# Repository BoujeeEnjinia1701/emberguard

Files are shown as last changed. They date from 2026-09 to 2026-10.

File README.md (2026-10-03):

# EmberGuard

     

**Area:** Situational Field Hardware · **TRL:** 3 of 9 (proof of concept on paper) · **Value-engineering target:** $605 USD (estimated kit cost $707) · **Difficulty:** 3 of 5

Gutter-corner thermal sensors and a weather mast that detect ember showers and trigger gutter and eave sprinkler zones.

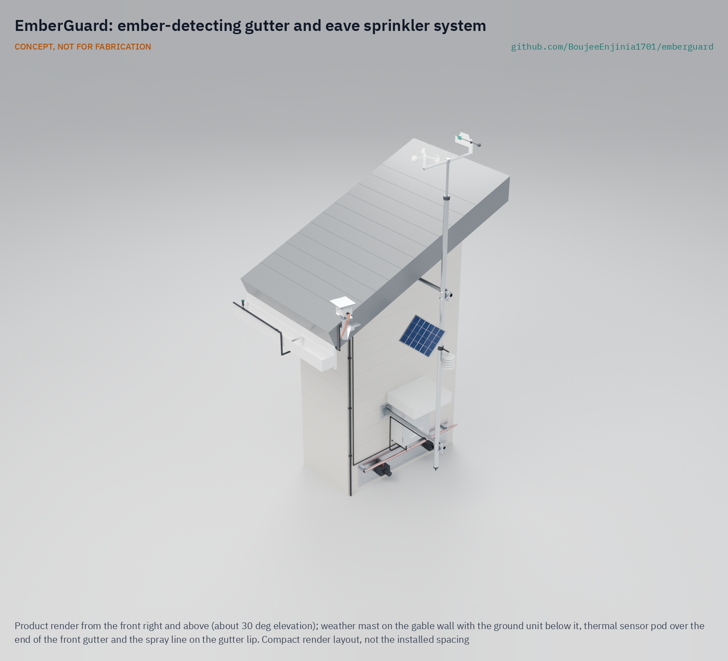
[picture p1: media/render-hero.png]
EmberGuard: ember-detecting gutter and eave sprinkler system, product render


[Exploded render](media/render-exploded.png) · [Detail render](media/render-detail.png) · [Interactive 3D model](media/viewer.html) · [Concept blueprint (PDF)](media/concept-blueprint.pdf) · [General arrangement EGD-DWG-001 (PDF)](cad/drawings/EGD-DWG-001.pdf) · [Sizing calculations](docs/04-calcs/01-sizing.md) · [Prototype build plan](docs/05-build-plan.md) · [Design decisions](docs/06-design-decisions.md) · [Review note](docs/REVIEW.md)

## Concept rationale

Most houses lost in wildland fires are lit by embers that lodge in gutters and at roof edges, often hours before or after the flame front and while the house is empty. EmberGuard therefore aims small and early: two low-cost thermal arrays look straight along the gutters from pods at their ends, a weather mast decides when fire weather has arrived, and a 4 L/min micro-sprinkler line wets only the strip where embers collect. Sensing embers rather than running on a timer keeps water use within a household tank and away from the hydrant supply that fire crews need.

The design is open and garage-buildable because the people most exposed are often the least able to buy a commercial exterior sprinkler system. Every part is an off-the-shelf sensor, irrigation valve or weather-station spare, the kit runs on 12 V with no mains work or roof penetrations, and the calculations, model and bill of materials are published so that neighbourhood groups, fire agencies and researchers can check the claims and the misses.

## Burning platform

Extreme wildfires are becoming more common. The UN Environment Programme projects a global increase in extreme fires of up to 14 % by 2030, 30 % by 2050 and 50 % by 2100 ([UNEP, 2022](https://www.unep.org/news-and-stories/press-release/number-wildfires-rise-50-cent-2100-and-governments-are-not-prepared)). At the same time more homes sit where fire can reach them: in the United States the wildland-urban interface grew from 30.8 million to 43.4 million homes between 1990 and 2010, a 41 % increase ([Radeloff et al. 2018, *PNAS*](https://doi.org/10.1073/pnas.1718850115)).

Embers are what turn a wildfire into a town fire. In the 2018 Camp Fire, showers of burning debris carried ahead of the main fire ignited buildings in Paradise, California; the fire killed 85 people and destroyed more than 18,000 buildings ([NIST, 2021](https://www.nist.gov/news-events/news/2021/02/new-timeline-deadliest-california-wildfire-could-guide-lifesaving-research)). Australia's 2019 to 2020 bushfires destroyed more than 3,000 homes ([Royal Commission into National Natural Disaster Arrangements, 2020](https://naturaldisaster.royalcommission.gov.au/publications/html-report/foreword)).

## Where it could be used

### By industry

| Industry | Use |
| --- | --- |
| Residential housing in fire-prone areas | Automatic wetting of gutters and eaves while the household is evacuated |
| Home insurance and mitigation programmes | An open, auditable reference design for studying low-cost ember defense retrofits |
| Agriculture and wine | Protecting sheds, barns and packing houses on tank water at the edge of bush or forest |
| Tourism and parks | Unattended lodges, huts and campground buildings in forest settings |
| Wildfire research | Logged ember arrival times, wind and valve actions from individual houses |

### By country or region

| Country or region | Why it matters there |
| --- | --- |
| United States (California and the West) | The Camp Fire destroyed more than 18,000 buildings, many ignited by embers blown ahead of the front ([NIST, 2021](https://www.nist.gov/news-events/news/2021/02/new-timeline-deadliest-california-wildfire-could-guide-lifesaving-research)) |
| Canada | More than 6,000 fires burned about 15 million hectares in 2023, over twice the previous record ([Natural Resources Canada](https://natural-resources.canada.ca/stories/simply-science/canada-s-record-breaking-wildfires-2023-fiery-wake-call)) |
| Australia | The 2019 to 2020 bushfires destroyed more than 3,000 homes ([Royal Commission, 2020](https://naturaldisaster.royalcommission.gov.au/publications/html-report/foreword)); many rural homes rely on tank water |
| Chile | Fires around Viña del Mar in February 2024 killed at least 122 people by 5 February ([UN Connecting Business initiative](https://www.connectingbusiness.org/ourwork/emergencies/chile-wildfires-2024)) |
| South Africa | The 2017 Knysna fires destroyed or damaged 1,059 formal and 385 informal homes, with ember attack igniting secondary fires across rivers and highways ([*International Journal of Disaster Risk Reduction*, 2023](https://www.sciencedirect.com/science/article/pii/S2212420923000985)) |
| Greece (Mediterranean Europe) | The July 2018 fire in the seaside village of Mati, near Athens, killed at least 98 people and destroyed thousands of houses and vehicles ([European Parliament, 2018](https://www.europarl.europa.eu/doceo/document/B-8-2018-0391_EN.html); [NOAA Climate.gov, 2018](https://www.climate.gov/news-features/event-tracker/strong-winds-whip-deadly-wildfires-greece-late-july-2018)) |

## What sparked the idea

The idea traces back to the survey that CSIRO building researchers made after the Ash Wednesday bushfires of 16 February 1983. Caird Ramsay and colleagues examined some 1,150 burnt and surviving houses in the Otway Ranges and found that houses were most often set alight by burning debris, embers of bark, twigs and leaves borne on the wind, lodging in gaps, at ridges and at gutters. They also found that people played a significant role in house survival, because a few buckets of water and wet mops were enough if a small fire was attacked early ([CSIRO, *Ecos* 43, 1985](https://www.aidr.org.au/media/4774/ecos_lessons-from-ash-wednesday.pdf)). EmberGuard asks whether a machine can supply that small, early wetting at the places where embers lodge, so that nobody has to stay behind to do it.

## Problem

Wildfire embers ignite homes well ahead of the fire front, most often in gutters, on roof edges and in debris near the eaves, while the house is empty and the power may be off. Commercial exterior sprinkler systems exist but are costly and closed, and timer-based sprinklers waste water that fire crews need.

## Concept

Gutter-corner thermal sensors and a weather mast that detect ember showers and trigger gutter and eave sprinkler zones.

Two small sensor pods at the gable-end corners of the gutters each hold a thermal array camera that looks straight along its gutter, and a slim weather mast at the gable carries an anemometer, wind vane, humidity sensor and solar panel. The system arms itself in fire weather, and when a pod sees a hot spot or a burst of hot specks it sprays the gutter lips at a steady 4 L/min, running only the leeward line in wind. It runs for three days armed on a small LiFePO4 battery with solar top-up.

The TRL 3 calculations (EGD-CAL-001 v0.6) confirm about 965 L per 4 h ember event, water at the farthest head within 54 s, a battery with a wide margin and a strong mast, and show that the pods see the inside of each open gutter along its length. They also show that hanger straps hide deep gutter debris beyond about 8 m, that single embers are caught to 8.8 m only when centred in a pixel, and that the leeward eave still gets too little water in the design wind. Making the design buildable (EGD-DDR-003) and the enclosure decisions of 2026-10-02 (a folded white sun shade and a charge controller that stops charging above 45 °C) bring the priced kit to an estimated $707 against the $605 value-engineering target set on 2026-09-26, USD 102 over; the savings worth trying are in the design decisions register. Paper studies of coarser spray and of pods raised to 1 m above the gutter lip left the design unchanged. The other findings are open questions for the next revision, listed in the [review note](docs/REVIEW.md).

Full design precis: [docs/02-concept.md](docs/02-concept.md)

## Key components

- Gable-end weather mast on two standoffs with crossover plates
- Two gutter-corner sensor pods with heat hoods and lens hoods, each with a thermal array sensor (32 x 24 pixels), on arms from cleats on the roof verge
- Anemometer, wind vane, temperature and humidity sensor
- Controller with 12.8 V 10 Ah LiFePO4 battery in a light-coloured steel enclosure under a folded white sun shade, and a 10 W solar panel with a charge controller that stops charging above 45 °C
- Two 12 V normally closed zone valves and a pressure transducer on a wall-mounted valve board
- Pump-start dry contact for an existing pump
- Micro-sprinkler lines on both gutter lips
- Mast earthing kit

The priced bill of materials is in [bom/bom.csv](bom/bom.csv). The parametric model is `cad/src/model.py`, with STEP and STL exports in `cad/step/` and `cad/stl/`.

## Building the prototype

The concept has been made buildable (decision record [EGD-DDR-003](docs/decisions/0003-design-for-construction.md)): every part now has a fixing and a way to be made in a small workshop, and the model checks that nothing overlaps and nothing stands in the thermal sensors' view. The [prototype build plan](docs/05-build-plan.md) shows how to make each of the 14 made or drilled components and fit the kit to a house in 18 steps, with a picture for every component, joint and step. It is a plan, not a record of a build; building and testing to it is TRL 4 work. Every decision is indexed in the [design decisions register](docs/06-design-decisions.md).

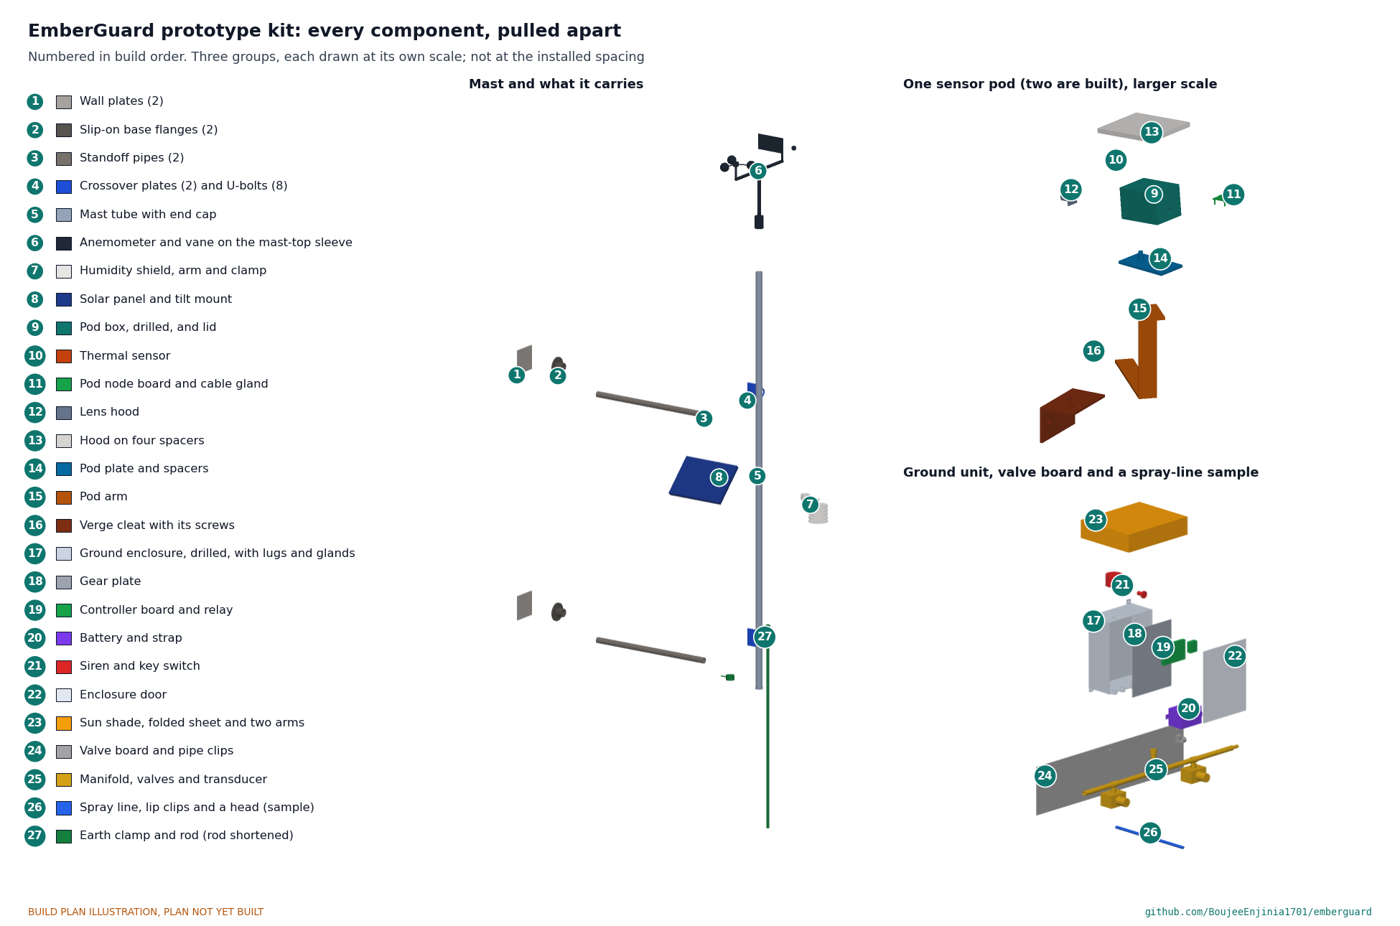
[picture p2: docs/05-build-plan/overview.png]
EmberGuard prototype kit, every component pulled apart and numbered in build order


## Safety

> Not a substitute for evacuation orders, home hardening or professional fire protection. Leave when told to leave. Installation involves work at height. The kit is 12 V DC only; a mains pump keeps its own certified controls. The LiFePO4 battery must be fused and enclosed, and the mast must be earthed against lightning. See the safety section of the precis.

## Repository layout

| Folder | Contents |
| --- | --- |
| `docs/` | Problem, concept, requirements, calculations and design decisions |
| `cad/src/` | build123d Python source, the source of truth for all geometry |
| `cad/step/`, `cad/stl/` | Exported models for FreeCAD, other CAD tools and printing |
| `cad/drawings/` | 2D sketches and dimensioned drawings |
| `bom/` | Bill of materials |
| `electronics/` | KiCad schematics and PCB layouts |
| `firmware/` | Microcontroller code |
| `media/` | Renders, perspectives and photos |
| `build-log/` | Dated prototyping notes |

## Documentation

Controlled documents follow the portfolio [documentation standard](.kit/STANDARDS.md). Each carries a document ID (EGD-PRC-001 for the precis), a version and a revision history. Branded PDFs are built with `python .kit/render.py` and attached to GitHub Releases when a document is tagged, for example `EGD-PRC-001/v1.0`.

## Credits

Designed by Amish Chadha, with contributions from Ashok Kumar Chadha. See [CONTRIBUTORS.md](CONTRIBUTORS.md) for roles. To cite this design, use [CITATION.cff](CITATION.cff) (GitHub shows it as "Cite this repository").

AI assistance (Claude) was used to accelerate concept renders, prototype documentation and first-pass sizing calculations. Design direction and all decisions are Amish Chadha's, recorded in this repository's decision records (`docs/decisions/`).

## Licenses

- **Hardware** (CAD, drawings, BOM, electronics): [CERN-OHL-S v2](LICENSE)
- **Software** (firmware, scripts, notebooks): [MIT](LICENSE-SOFTWARE)

A project of the [Design Molecule](https://designmolecule.com) lab.

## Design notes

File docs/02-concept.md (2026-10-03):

---
doc_id: EGD-PRC-001
title: EmberGuard design precis
project: EmberGuard
doc_type: Design precis
version: "0.9"
status: Draft
date: '2026-10-02'
author: Amish Chadha
license: CERN-OHL-S-2.0
revisions:
- version: "0.1"
  date: '2026-09-24'
  author: Amish Chadha
  change: Initial scaffold
- version: "0.2"
  date: '2026-09-25'
  author: Amish Chadha
  change: Populate to TRL 2 (architecture, components, first-order numbers, safety, media)
- version: "0.3"
  date: '2026-09-25'
  author: Amish Chadha
  change: TRL 3. Record Amish's decisions (EGD-DDR-001); numbers checked against EGD-CAL-001; gutter blind spot reported; parametric model, drawing EGD-DWG-001 and priced BOM
- version: "0.4"
  date: '2026-09-25'
  author: Amish Chadha
  change: Recommendations accepted by Amish (DDR-002). Thermal sensors moved to gutter-corner pods, 2 K trigger, leeward-only spray rule, 10 Ah battery; numbers from EGD-CAL-001 v0.2
- version: "0.5"
  date: '2026-09-26'
  author: Amish Chadha
  change: Budget approved by Amish ($605)
- version: "0.6"
  date: '2026-10-01'
  author: Amish Chadha
  change: Design made buildable (EGD-DDR-003); components, numbers and cost from EGD-CAL-001 v0.4; drawing at Rev P4; build plan and design decisions register added
- version: "0.7"
  date: '2026-10-01'
  author: Amish Chadha
  change: Budget treated as a value-engineering target
- version: "0.8"
  date: '2026-10-02'
  author: Amish Chadha
  change: "Decisions of 2026-10-02 carried in: enclosure finish and siting, 45 \u00b0C charge limit, gutter guards, leeward wetting study, third sensor later, opt-in data sharing"
- version: "0.9"
  date: '2026-10-02'
  author: Amish Chadha
  change: "Approved follow-ups carried out: sun shade (item 18) and 45 \u00b0C charge cut-off priced and modelled; enclosure temperature, shade wind load and the two paper studies from EGD-CAL-001 v0.6; cost $707; drawing Rev P5"
---

# EmberGuard design precis

EmberGuard pairs a slim weather mast at one gable end with two small thermal sensor pods at the gable-end corners of the gutters. Each pod sits 200 mm beyond the end of its gutter and 500 mm above the lip and looks straight down the gutter, so a 32 x 24 pixel thermal array sees the debris inside it and the first metre of roof. The mast carries a cup anemometer, a wind vane, a humidity sensor and a small solar panel, and they decide when fire weather has arrived. When the system is armed and sees a hot spot or a burst of hot specks, it opens 12 V valves feeding a line of micro-sprinklers clipped to each gutter lip, wetting the gutter, fascia and first metre of roof. In wind, only the leeward line runs. The TRL 3 calculations (EGD-CAL-001 v0.3) confirm a steady 4 L/min draw, about 965 L per 4 h ember event, water at the farthest head 55 s after detection, a battery with a wide margin and a strong mast. They also show what is still missing. Hanger straps across the gutter shadow debris that sits deep in it beyond about 8 m. A 600 °C ember reaches the 2 K trigger to 8.8 m only when it is centred in a pixel. The leeward eave still gets far less than 5 mm/h in the 30 km/h design wind. Making the design buildable (EGD-DDR-003) added flanges, crossover plates, pod mounts, a valve board and fixings, so the priced kit now costs an estimated $689 against the $605 value-engineering target set on 2026-09-26, USD 84 over; the savings worth trying are in the design decisions register (EGD-DEC-001). The prototype build plan is EGD-BLD-001 (`docs/05-build-plan.md`). The general arrangement is drawing EGD-DWG-001 Rev P4 (`cad/drawings/EGD-DWG-001.pdf`), generated from `cad/src/model.py`. This revision records the recommendations Amish accepted on 2026-09-25 (EGD-DDR-002): the pods replace the ridge-line sensor head, which could not see into the gutters at all.

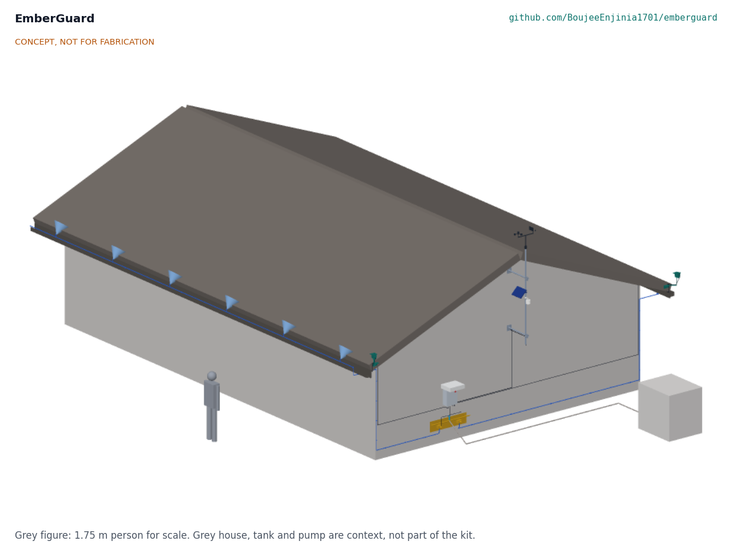
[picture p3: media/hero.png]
Hero render


*Figure 1. EmberGuard on the 12 x 8 m reference house, with a 1.75 m person for scale. Weather mast at the east gable, a sensor pod at the east end of each gutter, ground unit and valves on the gable wall, spray lines on both gutters (front spray envelopes shown in blue). Grey house, tank and pump are context. Rendered from the parametric model.*

## How it works

1. **Watch.** Outside fire weather the controller samples wind, wind direction, air temperature and humidity once a minute and sleeps between samples.
2. **Arm.** It arms when sustained wind reaches 30 km/h (or gusts 50 km/h) with relative humidity at or below 20 % for 10 min, or when the owner arms it by key switch or phone. These defaults resemble common Red Flag conditions, which vary by region, and are adjustable. Once armed, it stays armed for at least 6 h and runs both pod sensors at 4 frames per second.
3. **Detect.** Each sensor's frames are compared with a slowly updated background. Two patterns count as embers:
   - a **persistent hot spot**: a cluster of 1 to 4 pixels at least 2 K above its background for 5 s or more (decided, EGD-DDR-002, O5; was 5 K), which is what a landed ember or smouldering debris looks like;
   - an **ember shower**: 10 or more short hot flickers per minute across the view, from embers in flight or bouncing on the roof.
   Sun-heated roofing warms slowly and over large areas, so it is rejected by the small-cluster and rate-of-rise tests.
4. **Wet.** On a detection, the valve on the side of the detection opens first so its line fills within 47 to 54 s at 4 L/min (EGD-CAL-001, C3). In calm air the zones then alternate every 30 s. When the wind vane and anemometer show more than 2 m/s of wind across the eaves, only the leeward zone runs, continuously at 4 L/min, because wind drift starves the leeward eave; a detection on the windward side returns the system to alternating zones (decided, EGD-DDR-002, O4; EGD-CAL-001, C10). Either way the supply sees a steady 4 L/min. Spraying continues until 30 min after the last detection. A pressure transducer confirms that water is flowing; a dry-contact relay can start a pump that runs on its own supply.
5. **Fail safe.** If sensor data stops while armed (for example a pod is damaged by heat), the controller assumes the worst and sprays in the same cycle until the battery or water runs out. Loss of controller power closes the normally closed valves, which saves the tank.
6. **Tell.** A siren and status light at the ground unit, and a phone alert when a network is available, report arming, spraying and faults. An event log records detections, wind and valve actions for later study.

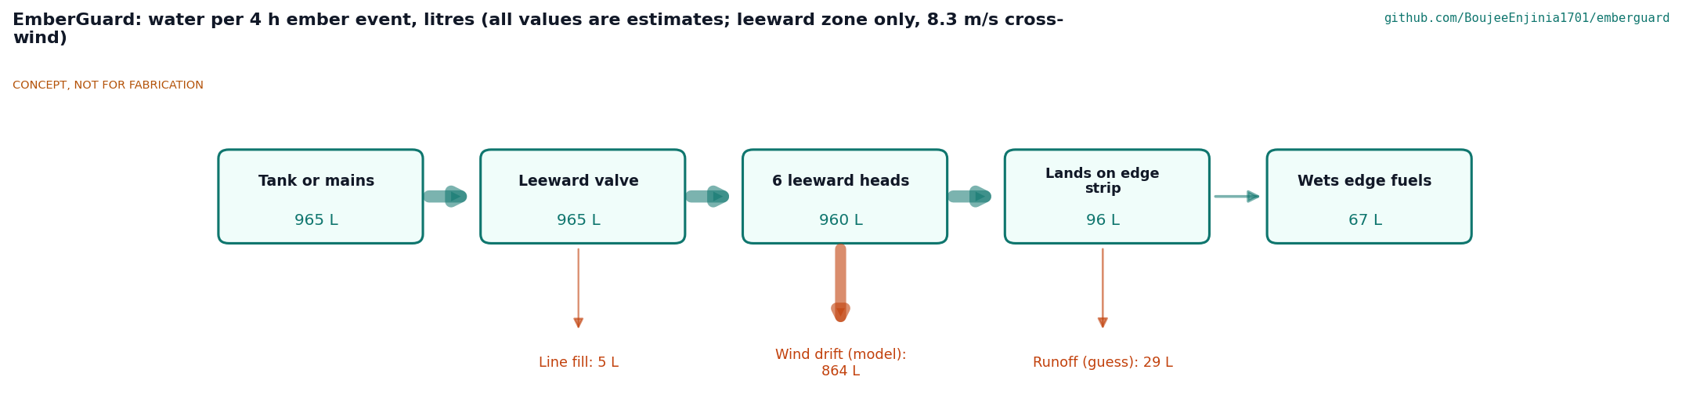
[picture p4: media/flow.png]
Water flow


*Figure 2. Water per 4 h ember event in the 30 km/h design wind. All values are estimates: the six leeward heads at 40 L/h running continuously under the leeward-only rule, wind drift from the screening model in EGD-CAL-001 v0.2 at an 8.3 m/s cross-wind (10 % on target on the leeward eave), and a guess at runoff from the gutter and roof edge. The figure shows why R6 is still not met.*

## Main components

Table 1. Main components. Numbers match `bom/bom.csv` and Figure 4. Items 16 and 17 are not shown in Figure 4.

| # | Component | Proposed choice | Notes |
| --- | --- | --- | --- |
| 1 | Mast, standoffs and crossover plates | 40 x 2 mm 6061-T6 aluminium tube, 2.45 m, held 700 mm off the gable wall by two DN25 galvanized pipe standoffs in slip-on flanges on aluminium wall plates, joined to the mast by crossover plates and U-bolts; cable inside the tube | Carries the weather sensors and solar panel; top 4.70 m above ground |
| 2 | Sensor pods (2) with hoods and brackets | Die-cast aluminium box about 100 x 80 x 70 mm with a stainless hood and a small pod node that digitizes the sensor; on a bent flat bar arm from a cleat screwed to the end of the roof overhang (decided, EGD-DDR-002, O3; mount EGD-DDR-003); sensor in a window in the pod wall under a short lens hood | Pod 200 mm beyond the gutter end, 500 mm above the lip, over the gutter centreline |
| 3 | Thermal array sensors (2) | MLX90640 BAB, 32 x 24 pixels, 55 x 35 degree field of view (decided, D2), one in each pod | Aimed along the gutter, 10 degrees toward the house and 5 degrees down |
| 4 | Anemometer and wind vane | Weather-station cup anemometer (pulse) and vane on a 460 mm crossarm | On the mast top, 5.0 m above ground, clear of the ridge |
| 5 | Temperature and humidity sensor | Digital sensor in a five-plate radiation shield | On the mast, clear of spray |
| 6 | Controller boards | Ground controller (ESP32 class) with valve drivers, linked over RS-485 to the two pod nodes | Firmware beyond a labelled sketch is TRL 4 work |
| 7 | Ground enclosure | Steel IP65 box about 160 x 320 x 400 mm on wall lugs on the gable wall, centre 1.15 m up, light-coloured; battery strapped on the floor, boards on the gear plate, cables in through bottom glands | Steel for heat and ember resistance; light finish, on the shadiest available wall, under the folded white shade (item 18) (decided 2026-10-02) |
| 8 | Battery | 12.8 V 10 Ah LiFePO4 with built-in BMS (decided, EGD-DDR-002, O5) | About 128 Wh nominal, 115 Wh usable |
| 9 | Solar panel | 10 W panel facing the equator at 45 degrees on a tilt bracket on the mast, with a LiFePO4 charge controller that stops charging above 45 °C (decided 2026-10-02) | Keeps the battery full between events; no credit taken during smoke |
| 10 | Zone valves A and B | Two 12 V DC normally closed solenoid valves, each on its own tee under a manifold on a valve board on the gable wall (decided, D9) | Front and back eave; closed on power loss; zero-minimum-pressure type |
| 11 | Pressure transducer | 0 to 10 bar, 0.5 to 4.5 V | Confirms water flow; warns of a dry supply |
| 12 | Pump-start relay | Isolated dry contact | Signals the pump's own certified controls; no mains inside EmberGuard |
| 13 | Mast and pod cables | Shielded outdoor cables; heat sleeve at each pod | Mast: wind, humidity and solar; pods: power and RS-485 |
| 14 | Eave spray lines and heads | 16 mm UV-stable polyethylene line clipped to each gutter lip, six micro-sprinklers per eave, risers up the gable wall corner and under the gutter on clips; 17.5 m and 21.1 m per zone | Metal eave runs decided if the budget allows (D4); it does not, so they are a $110 priced option |
| 15 | Siren, status light and key switch | 12 V siren, LED beacon, keyed arm switch | Key switch also disarms |
| 16 | Hardware, fittings and valve board | Valve board, manifold, clips, glands, fuses, battery strap | Modelled except fuses and small fixings |
| 17 | Mast earthing kit | Earth rod, clamp, conductor and mast bond | Added at TRL 3 for lightning protection |
| 18 | Enclosure sun shade | Folded white 1 mm aluminium sheet, 360 x 440 mm with three 100 mm flaps, on two flat-bar arms bolted to the gable wall 1.48 m up; 70 mm above the siren | Added on 2026-10-02 (EGD-DEC-001); cuts the enclosure's sun load for R10 [F6] |

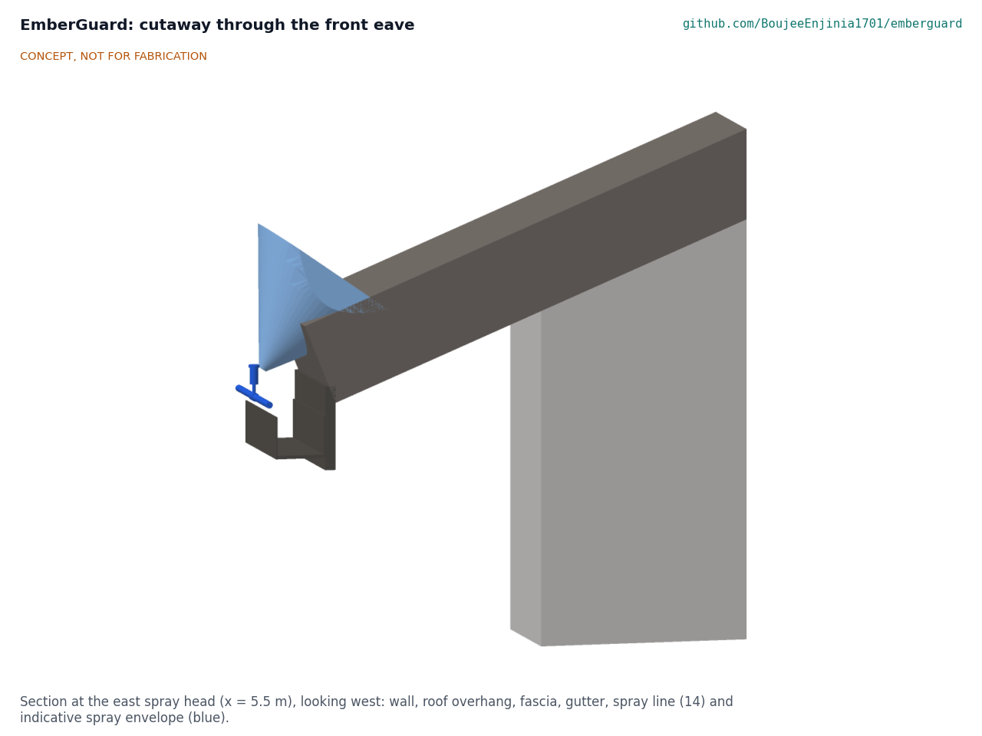
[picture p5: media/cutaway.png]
Cutaway


*Figure 3. Section through the front eave at the east spray head, looking west: wall, roof overhang, fascia, gutter, spray line and head (14) on the gutter lip, and the indicative spray envelope over the gutter and roof edge.*

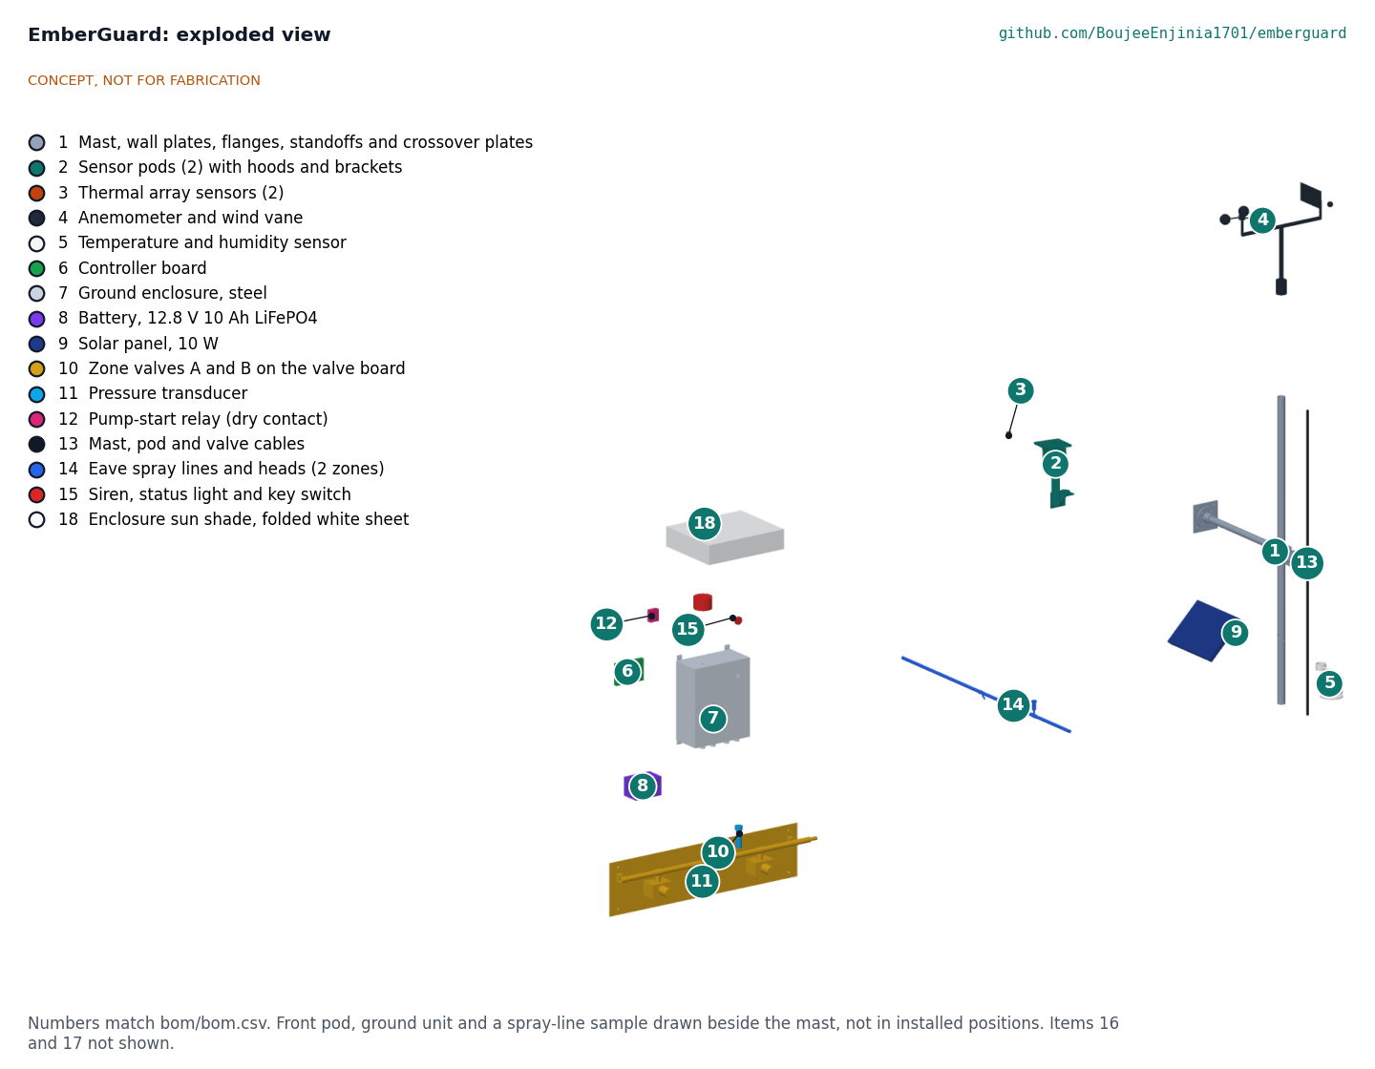
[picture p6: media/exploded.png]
Exploded view


*Figure 4. Exploded view with BOM numbers. The front sensor pod, the ground unit and a 1.4 m sample of spray line are drawn beside the mast, not in their installed positions.*

## Numbers checked at TRL 3

All values come from EGD-CAL-001 v0.6 (`docs/04-calcs/sizing.py`); the tags in brackets are its output lines. They are paper estimates.

Table 2. Key numbers.

| Quantity | Value | Basis | Requirement |
| --- | --- | --- | --- |
| Pixel footprint | 0.24 x 0.20 m at 8 m, 0.42 x 0.36 m at 14 m | 1.72 x 1.46 degree pixels [A1] | |
| Pod position | 200 mm beyond the gutter end, 500 mm above the lip (2.97 m above ground) | Model [A2] | |
| Gutter interior in view | 1.25 m to 12.95 m from the gutter end, both gutters (open gutter); range 1.5 to 13.1 m | Line of sight on the model [A3], [A5] | R3 met |
| Hanger straps every 750 mm | Debris 42 mm below the lip seen at 35 of 118 stations, none beyond 7.8 m; debris within 10 mm of the lip seen at 95 of 118 | [A4] | R1 **at risk** |
| Grazing angle on the debris | 7.4 degrees at 4 m, 3.8 degrees at 8 m, 2.4 degrees at 13 m | [A6] | |
| Former ridge-line head | Debris seen at 0 of 130 stations | [A7] | |
| 100 cm² spot at 300 °C | Flat on the debris: 6.7 K at 8 m, 1.6 K at 13 m; reaches the 2 K trigger to 12.1 m. Debris face 100 x 50 mm: 43 K at 8 m, seen to 41 m | 2 K trigger [B9] to [B11] | R1 **at risk** |
| 10 mm ember, 600 °C | Reaches 2 K to 8.8 m centred in a pixel, 4.4 m on a pixel corner (5.5 m and 2.8 m at the former 5 K) | [B6], [B7] | R2 **at risk** |
| Flow and application | 4 L/min per zone; 15.4 mm/h while running | [C1] | |
| Line fill | Water at the farthest head 47 s (A) and 54 s (B) after detection | Detection-side zone first [C3] | R5 met |
| Supply pressure | About 2.3 bar at the manifold | Friction and 2.1 m lift [C4] | |
| Water per event | 965 L (255 US gal) | 4 h at 4 L/min plus line fill [C5] | R7 met, 3.5 % margin |
| Net wetting, leeward-only rule | Leeward eave 1.5 mm/h at 8.3 m/s (0.8 mm/h alternating) and 5.1 mm/h at 4.2 m/s; windward eave dry until a windward detection, then 7.4 mm/h | Droplet screening model [C7], [C10] | R6 **not met** |
| Energy | 54.4 Wh for 72 h armed plus 13.1 Wh for 4 h spraying = 67.5 Wh | 0.76 W armed, 3.24 W spraying [D2] to [D4] | |
| Battery | 115.2 Wh usable at 25 °C, 103.7 Wh at 0 °C, 92.2 Wh at end of life | 12.8 V 10 Ah LiFePO4 [D4] | R8 met |
| Pump on its own battery (studied) | About 57 W, 229 Wh per event; a 25 Ah LiFePO4 pack or one SwapCell pack (1.6 events) | [D7] to [D9] | Out of kit scope (D6) |
| Mast at 120 km/h | 174 N; 31 N·m at the upper standoff; 14 MPa (factor 16.6) | [E2], [E3] | R10 wind met |
| Standoffs | 153 N reaction; 50 MPa in DN25 pipe (factor 4.7); about 535 N per wall anchor | [E4] | |
| Enclosure in sun at 60 °C | About 71 °C (mid-grey), 67 °C (light, sun on face and top), 63 °C (light, with the shade); charging stops above 45 °C | [F1], [F5], [F6] | R10 at risk |
| Pod arm at 120 km/h | About 8 MPa (factor 19); about 70 N pull per coach screw | [E5] | |
| Sun shade at 120 km/h | Up to 108 N of uplift; about 40 MPa in each arm (factor 4); about 320 N per wall screw | [E7] | |
| Studies on paper (design unchanged) | Coarser droplets give the leeward eave 4.6 mm/h at 8.3 m/s; a second leeward row would need 1,920 L per event; pods 1 m above the lip lose the first 1.2 m of each gutter and double the arm load | [C11] to [C14], [A8], [E6] | R6 still **not met** |
| Kit parts cost | $707 against the $605 value-engineering target | `bom/bom.csv` [G1] | R13 **over the value-engineering target by USD 102** |

## Key design choices

Amish decided the TRL 2 review items on 2026-09-25 by accepting each recommendation (EGD-DDR-001), and later the same day accepted the recommendations left open after TRL 3 (EGD-DDR-002). The choices below are therefore decided.

- **Thermal arrays, not simple flame sensors (decided, D2).** Near-infrared flame sensors respond to flames and sunlight and cannot say where a hot spot is. A 32 x 24 thermal array locates hot spots, measures their size and ignores sun-warmed roofing.
- **Watch the gutter from its end (decided, O3).** Landed embers and smouldering debris persist for seconds to minutes and are what actually ignites a house, and gutters are where they collect. A sensor above the ridge cannot see into a gutter behind the eave. A pod beyond the gutter end looks straight along it. Hanger straps still hide deep debris far from the pod.
- **Arm on weather, trigger on embers (decided, D7 and O5).** Adjustable defaults of 30 km/h sustained or 50 km/h gusts with humidity at or below 20 % for 10 min, plus manual and remote arming, reviewed with a local fire agency. Persistent-spot trigger 2 K, ten times the sensor noise at 4 Hz; its false-trigger rate needs recorded thermal video (TRL 4, on hold).
- **Weather mast at the gable end (decided, D3).** The mast now carries only the wind, humidity and solar parts, clear of the ridge.
- **Leeward zone in wind (decided, O4).** Two zones halve the peak flow so a small pump can keep up, and suit a 1,000 L tank (decided, D5). In wind only the leeward zone runs, because drift starves it; the windward eave then relies on its own detections.
- **Low-voltage kit, pump by dry contact (decided, D6).** No mains wiring on the house; the pump keeps its own certified controls and its own power, provided by the homeowner.
- **Fail to wet on sensor loss (decided, D8), fail closed on power loss (decided, D9).** Losing a pod during the fire is likely; losing the controller should not drain the tank.
- **Battery with margin (decided, O5).** A 10 Ah pack covers 72 h armed and 4 h of spraying with 37 % to spare at end of life.
- **Polyethylene eave runs (D4).** Metal eave runs were chosen if the budget allowed; it does not, so they are a priced option.

## Safety

> **Safety:** EmberGuard is not a substitute for evacuation orders, home hardening or professional fire protection. Leave when told to leave. Never stay behind to operate, watch or repair the system during a fire.

> **Safety:** Installing the mast, sensor pods and spray lines means working at height near a roof edge. Use a stable ladder, a second person and fall protection where required; do not work on a wet or mossy roof.

> **Safety:** Water, pumps and electricity. The kit is 12 V DC only. Any mains-powered pump must keep its own certified controls and ground-fault protection; the EmberGuard relay only signals it through an isolated dry contact. Do not wire EmberGuard into mains circuits.

> **Safety:** The LiFePO4 battery is safer than other lithium chemistries but can still overheat if shorted or damaged. Use a pack with a built-in BMS and low-temperature charge cut-off, fuse the battery output, and keep the battery inside the steel enclosure. In full sun at 60 °C ambient a mid-grey enclosure reaches about 71 °C (about 67 °C with a light finish and 63 °C under the white sun shade), above the LiFePO4 limits of 60 °C for discharge and 45 °C for charge: give the enclosure a light finish and the sun shade, mount it on the shadiest available wall, and use a charge controller that stops charging above 45 °C.

> **Safety:** A tall metal mast on the gable is exposed to lightning. Bond it to a proper earth electrode (BOM item 17) and follow local lightning-protection practice. The wall anchors carry about 535 N each at 120 km/h; check them for each wall. The sensor pods stand on arms beyond the gutter ends; screw their cleats into a sound timber verge board and check them after storms.

> **Safety:** Automatic sprinklers on mains water can reduce pressure for firefighters. Prefer a dedicated tank; if using mains, keep the flow at or below 4 L/min and follow local fire-agency guidance.

> **Safety:** False reassurance is a hazard in itself. Gutter hanger straps hide deep debris far from the pods, the leeward eave gets little water in strong wind, the system can miss embers outside its view (vents, decks, the far gable), and it can fail in fire conditions. Keep gutters clean, fit gutter guards where deep debris collects (listed in the installation notes), and harden the house as if EmberGuard were not there.

## Open questions

Decisions still to be made are indexed in the design decisions register (`docs/06-design-decisions.md`, EGD-DEC-001).

- [x] How should deep gutter debris beyond the hanger-strap shadow be watched? Decided 2026-10-02 (EGD-DDR-002, N3): pods raised to about 1 m above the gutter lip were studied on paper (EGD-CAL-001, [A8], [E6]). They see over the straps better (59 of 106 stations against 35 of 118) but lose the first 1.2 m of each gutter and double the arm's wind load, so the pods stay 500 mm above the lip. Gutter guards are in the installation notes of the build plan.
- [ ] How can the leeward eave get 5 mm/h in the design wind? Studied on paper (EGD-CAL-001, [C11] to [C14]), with R6 kept at the 30 km/h design wind: coarser droplets give 4.6 mm/h at 8.3 m/s, just short; lower angles put the water on the fascia and roof edge only; a second leeward row would need 1,920 L per event. Adopting a coarser-spray head is for Amish and a spray trial. Does real recirculation behind the ridge help?
- [ ] Can a 2 K persistent-spot threshold reject sun glints, hot vents, chimneys, birds and vehicles? This needs recorded thermal video, at TRL 4 or later (on hold).
- [ ] How long do ember showers last at a single house, and is a 4 h spraying design case reasonable?
- [ ] How hot do the pods get under radiant heat and ember attack at the gutters, and for how long do they keep working?
- [x] Budget for the $605 kit: set to $605 by Amish on 2026-09-26 (N1).
- [x] Should a third sensor cover vents, decks and the far gable? Left to a later version (decided 2026-10-02).
- [x] Should EmberGuard log and share anonymised ember arrival data with WUI researchers? Opt-in only, with the first partner agreeing what is shared and with whom (decided 2026-10-02).

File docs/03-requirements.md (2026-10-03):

---
doc_id: EGD-REQ-001
title: EmberGuard requirements
project: EmberGuard
doc_type: Requirements
version: "0.9"
status: Draft
date: '2026-10-02'
author: Amish Chadha
license: CERN-OHL-S-2.0
revisions:
- version: "0.1"
  date: '2026-09-24'
  author: Amish Chadha
  change: Initial scaffold
- version: "0.2"
  date: '2026-09-25'
  author: Amish Chadha
  change: First measurable requirements for TRL 2, reference house and status against the concept
- version: "0.3"
  date: '2026-09-25'
  author: Amish Chadha
  change: TRL 3. Record Amish's decisions (EGD-DDR-001); R8 redefined (pump power out of kit scope), R13 at $425, R4 defaults decided; status of every requirement from EGD-CAL-001
- version: "0.4"
  date: '2026-09-25'
  author: Amish Chadha
  change: Recommendations accepted by Amish (DDR-002). R13 at $575; status from EGD-CAL-001 v0.2 for the gutter-corner pods, 2 K trigger, leeward-only rule and 10 Ah battery
- version: "0.5"
  date: '2026-09-26'
  author: Amish Chadha
  change: Budget approved by Amish
- version: "0.6"
  date: '2026-10-01'
  author: Amish Chadha
  change: Status from EGD-CAL-001 v0.4 after the design was made buildable (EGD-DDR-003); R13 met to not met ($689 against $605)
- version: "0.7"
  date: '2026-10-01'
  author: Amish Chadha
  change: Budget treated as a value-engineering target
- version: "0.8"
  date: '2026-10-02'
  author: Amish Chadha
  change: "R1, R6 and R10 notes: decisions of 2026-10-02 (EGD-DEC-001); no requirement changed status"
- version: "0.9"
  date: '2026-10-02'
  author: Amish Chadha
  change: "Status from EGD-CAL-001 v0.6: sun shade, 45 \u00b0C charge cut-off, paper studies for R6; R13 cost $707 (USD 102 over the target); no requirement changed status"
---

# EmberGuard requirements

These requirements are proposals for review, not user-validated needs. Version 0.3 recorded Amish's decisions of 2026-09-25 (EGD-DDR-001): the budget in R13 went to $425 (D1), R8 covers the kit's own battery and makes grid-independent water an installation precondition (D6), and the arming defaults in R4 are decided (D7). Version 0.4 records his acceptance of the remaining recommendations on the same day (EGD-DDR-002): the budget is $575 (O2), the thermal sensors move to pods at the gutter corners (O3), only the leeward zone runs in wind (O4), and the trigger is 2 K with a 10 Ah battery (O5). Version 0.5 records the budget of $605 that Amish approved on 2026-09-26 to cover the priced BOM (EGD-DDR-002). Version 0.6 takes the status from EGD-CAL-001 v0.4 and `docs/04-calcs/results.csv`, after the design was made buildable (EGD-DDR-003): the parts added for construction bring the kit to $689, so R13 is USD 84 over the value-engineering target of $605. One requirement is **not met** (R6), one is **over its value-engineering target** (R13), three are **at risk** (R1, R2 and R10), one is not verifiable at TRL 3 (R11) and seven are met. The pods fix the gutter blind spot of the ridge-line head, but hanger straps still shadow deep debris, and the leeward eave stays short of water in the design wind.

Table 1. Requirements.

| ID | Requirement | Target | Verification | Status at TRL 3 (EGD-CAL-001) |
| --- | --- | --- | --- | --- |
| R1 | Detect a smouldering ignition on a watched gutter or roof edge | A 100 cm² (15.5 in²) hot spot at 300 °C or hotter, anywhere along the watched gutters from 1.5 m to 13 m from the mast, within 10 s | Radiometric calculation from sensor field of view and noise; later a heated-target trial | **At risk:** from the gutter-corner pods (decided, EGD-DDR-002, O3) a 100 x 50 mm hot debris face reaches the 2 K trigger to 41 m, and a flat spot on the debris reaches it to 12.1 m (1.6 K at 13 m). Hanger straps across the gutter top shadow debris 42 mm below the lip at 83 of 118 stations and everywhere beyond 7.8 m; debris within 10 mm of the lip is seen at 95 of 118 (EGD-CAL-001 v0.2, A4, B9 to B11) Decided 2026-10-02: R1 is not restated; pods raised to about 1 m above the lip are studied on paper, and gutter guards are listed in the installation notes (EGD-DEC-001). |
| R2 | Detect single landed embers | A 10 mm glowing ember at 600 °C or hotter within 8 m of the mast, within 10 s | Same as R1 | **At risk:** with the 2 K trigger (decided, O5) a 600 °C ember is detected to 8.8 m centred in a pixel but only 4.4 m on a pixel corner; the false-trigger rate at 2 K is unknown (B6) |
| R3 | Watch both roof planes | Both eave gutters of the reference house, each from 1.5 m from the gable end to the far end | Line-of-sight check on the parametric model | Met: each pod sees the inside of its gutter from 1.25 m to 12.95 m from the gutter end, for an open gutter (A3, A5); see R1 for hanger straps |
| R4 | Arm only in fire weather | Automatic arming when sustained wind is 30 km/h (19 mph) or more, or gusts 50 km/h (31 mph) or more, with relative humidity 20 % or less for 10 min; manual and remote arming; defaults adjustable and reviewed with a local fire agency (decided, D7) | Design review of the arming logic | Met by design |
| R5 | Start water quickly | Water at the farthest head within 60 s of a confirmed detection | Line fill calculation | Met: 54 s for the longer zone, filling the detection-side zone first (C3) |
| R6 | Wet the gutter and roof edge | Net water on a 1.2 m wide strip along each eave (gutter, fascia and first metre of roof) of 5 mm/h or more, averaged over each spray cycle, at the design wind of 30 km/h | Droplet drift screening model; later a spray trial in wind | **Not met:** with the leeward-only rule (decided, O4) the leeward eave gets 1.5 mm/h at 8.3 m/s and 5.1 mm/h at 4.2 m/s; the windward eave is sprayed only after a windward detection, then 7.4 mm/h (C10). Decided 2026-10-02: R6 stays at the 30 km/h design wind. The paper study (EGD-CAL-001, C11 to C14) finds coarser droplets reach 4.6 mm/h at 8.3 m/s, just short; lower angles wet only the roof edge; a second leeward row would need 1,920 L per event; R6 stays not met |
| R7 | Use little water | Steady draw 4 L/min (1.1 US gal/min) or less; 1,000 L (264 US gal) or less for a 4 h ember event | Flow calculation from head ratings and duty cycle | Met: 4 L/min and 965 L, 3.5 % margin (C5) |
| R8 | Work through a grid outage (redefined, D6) | The kit battery alone runs sensing, logic and valves for 72 h armed plus 4 h of spraying, with no solar input. Water supply that does not depend on grid power (gravity feed, generator or battery pump) is an installation precondition provided by the homeowner and is outside the kit | Energy budget; installation check of the water supply | Met: 67.5 Wh needed; the 10 Ah battery (decided, O5) gives 115.2 Wh usable at 25 °C, 103.7 Wh at 0 °C and 92.2 Wh at end of life (D4) |
| R9 | Fail safely | Loss of sensor data while armed starts spraying (decided, D8); low battery, no water pressure or a faulty valve raises an alarm; power loss closes the normally closed valves (decided, D9) | Failure modes review | Met by design |
| R10 | Survive fire weather until the front arrives | Mast and sensor pods survive gusts of 120 km/h (75 mph); electronics operate from -10 to 60 °C ambient; sensors shaded from sun and radiant heat | Wind load and thermal calculations | **At risk:** mast 14 MPa (factor 16.6), standoffs factor 4.7 and pod arms factor 19 met; the enclosure reaches about 63 °C in sun at 60 °C ambient with the light finish and the white shade (71 °C mid-grey), above the battery's limits, so charging stops above 45 °C; the pods sit 0.5 m above the gutters, where embers land; radiant heat not estimated (E3, E4, F1, F4). Decided 2026-10-02 and carried out: a light finish, the shadiest available wall, a folded white sun shade (BOM line 18) and a charge controller that stops charging above 45 °C (EGD-DEC-001; F5, F6, E7) |
| R11 | Install without roof work or mains wiring | Mast, cable and spray lines fixed to walls, fascia and gutter lips with clamps; no roof penetrations; 12 V DC only; installable by two people with hand tools in 6 h or less | Design review; later a timed trial | Not verifiable at TRL 3: met by design except the install time |
| R12 | Tell people what it is doing | Local siren and status light; phone alert when armed, spraying, faulted or low on battery when a network is available; event log of detections, wind and valve actions | Design review | Met by design; phone alerts need a working network |
| R13 | Stay near the value-engineering target | Kit parts at or below the value-engineering target of $605 (a hypothetical control target; set at $300, then $425, D1, then $575, EGD-DDR-002, O2, then $605, approved by Amish on 2026-09-26), excluding the water source and pump, and excluding priced options | Priced BOM | **Over the value-engineering target by USD 102:** $707 after the parts added for construction (EGD-DDR-003) and the 2026-10-02 enclosure decisions, 17 % over the $605 target (USD 102); savings to try are in EGD-DEC-001 (G1) |

## Reference house and assumptions

- **House.** Single storey, 12 x 8 m (39 x 26 ft) footprint, 2.7 m walls, gable roof at 22 degrees with the ridge along the long side, 500 mm overhangs, gutters along both long eaves (13 m each, 26 m total). The weather mast stands off one gable end at the ridge line; the two thermal sensors sit in pods beyond the gable-end corners of the gutters (EGD-DDR-002, O3).
- **Water.** A 1,000 L tank with a pump on its own supply (decided, D5). The supply must hold about 2.3 bar at the valve manifold at 4 L/min (EGD-CAL-001, C4). EmberGuard does not include the tank or pump.
- **Ember event.** 4 h of active spraying within a 72 h armed period. This is a design assumption, not a measured duration; real ember exposure varies from minutes to many hours.
- **Heads.** Six micro-sprinklers per eave at 2.2 m spacing, about 40 L/h each at 2 bar (typical catalogue figure for small irrigation heads, to be confirmed with a named part).
- **Wind drift.** Estimated at TRL 3 with a droplet screening model (EGD-CAL-001, section C) in place of the TRL 2 guess of 50 %. The leeward eave is the worst case, which is why only the leeward zone runs in wind (O4). The model is uncertain and needs a spray trial.
- **Gutters.** Open half-round or box gutters with hanger straps across the top every 750 mm (assumed), debris surface 42 mm below the lip.
- **Ember targets.** Emissivity 0.9, sensor band 8 to 14 µm, background 300 K. See EGD-CAL-001, section B.

> **Safety:** EmberGuard does not replace evacuation. Requirements R4 to R9 describe behaviour while the house is empty. Nothing in these requirements permits anyone to stay behind to operate or watch the system.

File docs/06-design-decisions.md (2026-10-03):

---
doc_id: EGD-DEC-001
title: EmberGuard design decisions register
project: EmberGuard
doc_type: Design decisions register
version: "0.4"
status: Draft
date: '2026-10-02'
author: Amish Chadha
license: CERN-OHL-S-2.0
revisions:
  - version: "0.1"
    date: '2026-10-01'
    author: Amish Chadha
    change: Register opened with the open decisions from the review note, the decision records and the build plan work
  - version: "0.2"
    date: '2026-10-01'
    author: Amish Chadha
    change: Budget treated as a value-engineering target
  - version: "0.3"
    date: '2026-10-02'
    author: Amish Chadha
    change: Amish approved the recommendations for open decisions 1 to 12 (EGD-DDR-003 accepted; pitch reworded); moved to decisions made
  - version: "0.4"
    date: '2026-10-02'
    author: Amish Chadha
    change: Approved follow-ups carried out; value engineering section updated to USD 707 with the sun shade and the 45 °C charge controller priced
---

# EmberGuard design decisions register

Every design decision still to be made, and every decision made, in one place. Each decision is argued in full in its decision record under `docs/decisions/`; this register is the index Amish works from. The build plan (`docs/05-build-plan.md`) describes the design as it stands and does not list open decisions.

## Open decisions

None. All open decisions were decided on 2026-10-02.

## To confirm when parts are bought

| # | What to confirm | Why it matters | Source |
| --- | --- | --- | --- |
| 1 | The thermal sensor breakout is no larger than 25 x 25 mm, with the sensor can centred and four corner holes | It mounts on the inside of the pod's west wall with its can in a 9.5 mm window | EGD-DDR-003, P6 |
| 2 | The die-cast pod box has walls of 4 mm or more and its lid screws into corner bosses | The sensor and lens hood screw into tapped holes in the wall; the hood spacers into the lid | EGD-DDR-003, P6, P7 |
| 3 | The slip-on base flange fits 33.7 mm pipe, its four holes lie on an 80 mm circle and it has set screws | The wall plate's flange holes and the standoff fit depend on it | EGD-DDR-003, P1 |
| 4 | The U-bolts' leg spacing for 40 mm tube and for 33.7 mm pipe | They set the eight holes in each crossover plate | EGD-DDR-003, P1 |
| 5 | The steel enclosure comes with a gear plate on studs and a four-lug wall kit | The battery strap, board standoffs and wall fixing use them | EGD-DDR-003, P9 |
| 6 | The solar panel frame accepts the pole-mount tilt bracket | The panel's only fixing | EGD-DDR-003, P3 |
| 7 | The zone valves have inlet and outlet in line, top and bottom, with the coil to one side | The valves hang from the manifold tees | EGD-DDR-003, P10 |
| 8 | The gutter-lip clips fit the gutter's lip profile | They carry the eave line | EGD-DDR-003, P11 |
| 9 | At the house: a sound timber verge board at each gutter end, a fascia lower edge for the riser clip, and a gable wall that takes the wall anchors (about 535 N pull each) | The pods, risers and mast fix to them | EGD-DDR-003, P1, P5, P11; EGD-CAL-001, E4 |
| 10 | The charge controller takes a battery temperature probe and stops charging above 45 °C | The enclosure reaches about 63 °C in sun at 60 °C ambient, above the pack's charge limit | BOM line 9; EGD-CAL-001, F6 |
| 11 | The gable wall takes two M6 plugs for the sun shade (about 320 N pull each at 120 km/h) | The shade's only fixing | BOM line 18; EGD-CAL-001, E7 |

## Value engineering

Value-engineering target: USD 605. Estimated cost of the constructable design: USD 707 (USD 102 over the target). The target is a hypothetical control target, not a limit. Main cost drivers and savings worth trying:

- Of the USD 102 over the target, USD 84 is the parts added to make the kit buildable (EGD-DDR-003): flanges, crossover plates and U-bolts (+USD 32), pod mounts and lens hoods (+USD 18), the panel tilt bracket (+USD 6), longer cables (+USD 3), and the valve board, clips, glands and strap (+USD 25).
- The largest lines are the two thermal sensors (USD 96), the mast, standoffs and crossover plates (USD 80), the two sensor pods (USD 74) and the spray lines and heads (USD 52).
- Decided on 2026-10-02 and now priced: the folded white shade for the ground enclosure (line 18, USD 14: sheet USD 5, flat bar USD 3, paint USD 2, screws, plugs and rivets USD 4) and a charge controller with a battery temperature probe that stops charging above 45 °C (line 9, USD 4 more).
- Savings worth trying, about USD 35 in all: bolt the flanges straight to the wall without wall plates (about USD 10, but the anchor pull roughly doubles and must be rechecked), a plywood valve board (about USD 12), and unbranded thermal breakouts (about USD 10 to USD 15).
- Metal eave runs would add USD 110 and are a priced option outside the kit, not a saving.

## Decisions made

| Date | Decision | Decided by | Record |
| --- | --- | --- | --- |
| 2026-09-25 | TRL 2 review items D1 to D9: budget $425, two MLX90640 thermal arrays, gable-end mast, metal eave runs if the budget allows (it did not), tank with its own pump, pump power out of scope, adjustable arming defaults, fail to wet on sensor loss, normally closed valves | Amish: "proceed with all of your recommendations across all batches. Make sure we don't proceed to TRL 4 on any of them." | EGD-DDR-001 |
| 2026-09-25 | O2 to O5: budget $575, thermal sensors in gutter-corner pods, leeward zone only in wind, 2 K trigger and 10 Ah battery | Amish: "i accept all your recommendations, go with them across all repos." | EGD-DDR-002 |
| 2026-09-26 | Budget set to $605 to cover the priced BOM (N1) | Amish: "i approve all the budget items." | EGD-DDR-002 |
| 2026-09-26 | EmberGuard chosen for the first batch of product renders | Amish | Review note, 2026-09-26 |
| 2026-10-02 | Design for construction accepted: the changes P1 to P12, as made, including P10, which feeds the two zone valves side by side | Amish: "i approve your recommendations for all 555 open decisions." | EGD-DDR-003, Table 1 (P1 to P12) |
| 2026-10-02 | No window in front of the sensor for the prototype; an ash-fouled lens case is included in the TRL 4 heated-target and ash trials, and the window is decided from that result | Amish: "i approve your recommendations for all 555 open decisions." | EGD-DDR-003, A2 |
| 2026-10-02 | Pod mount: the verge cleat now, with a sound timber verge confirmed at each site; a fascia-face bracket is drawn once the partner's houses are known | Amish: "i approve your recommendations for all 555 open decisions." | EGD-DDR-003, A3 |
| 2026-10-02 | Ground enclosure: a light finish and the shadiest available wall now; the folded white shade is designed at the next revision; the charge controller must stop charging above 45 °C | Amish: "i approve your recommendations for all 555 open decisions." | EGD-CAL-001, F1; review note, 2026-09-25 |
| 2026-10-02 | Leeward wetting: larger, lower-angle droplets and a second leeward row are studied on paper at the next revision; R6 stays at the 30 km/h design wind | Amish: "i approve your recommendations for all 555 open decisions." | EGD-DDR-002, N2 |
| 2026-10-02 | Deep gutter debris: raising the pods to about 1 m above the gutter lip is studied on paper (including the arm's wind load and ember exposure); gutter guards are listed in the installation notes now | Amish: "i approve your recommendations for all 555 open decisions." | EGD-DDR-002, N3 |
| 2026-10-02 | Pitch adopted: "Gutter-corner thermal sensors and a weather mast that detect ember showers and trigger gutter and eave sprinkler zones." | Amish: "i approve your recommendations for all 555 open decisions." | EGD-DDR-002, N4 |
| 2026-10-02 | First co-design partner to approach: a recognised Firewise USA neighbourhood group in a wildland-urban interface area whose houses have gable ends with timber verges; in Texas, through the Texas A&M Forest Service, which supports such groups | Amish: "i approve your recommendations for all 555 open decisions." | EGD-DDR-001, O1 |
| 2026-10-02 | Product render layout accepted as render-only, with captions saying the mast and ground unit are drawn closer than installed | Amish: "i approve your recommendations for all 555 open decisions." | Review note, 2026-09-26, item 1 |
| 2026-10-02 | Spray lines stay blue in the concept media; the BOM still specifies black line | Amish: "i approve your recommendations for all 555 open decisions." | Review note, 2026-09-26, item 5 |
| 2026-10-02 | A third sensor for vents, decks and the far gable is left to a later version | Amish: "i approve your recommendations for all 555 open decisions." | EGD-PRC-001, open questions |
| 2026-10-02 | Ember arrival data sharing is opt-in, with the first partner agreeing what is shared and with whom | Amish: "i approve your recommendations for all 555 open decisions." | EGD-PRC-001, open questions |

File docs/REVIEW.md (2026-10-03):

# Review note: EmberGuard

## Session 2026-09-25: /populate to a strong TRL 2 (overnight batch)

### What was done

- `docs/01-problem.md` (EGD-PRB-001 v0.2): the problem (ember ignition, timing, power and water in fire weather, cost of commercial systems), users and context, constraints, out of scope, prior work with inline sources, open questions. The scaffold had no co-design checklist, so none was kept or added.
- `docs/03-requirements.md` (EGD-REQ-001 v0.2): 13 measurable requirements (R1 to R13) with targets, planned verification and a concept status column; reference house and assumptions.
- `docs/02-concept.md` (EGD-PRC-001 v0.2): how it works (watch, arm, detect, wet, fail safe, tell), components table numbered to the BOM and exploded view, first-order numbers with assumptions, key design choices, safety section, open questions.
- `cad/src/concept_media.py`: massing model of a 12 x 8 m single-storey house (context) with the kit: gable-end mast, sensor head, two thermal sensors, anemometer and vane, humidity sensor, solar panel, ground enclosure with controller and battery, zone valves, pressure transducer, relay, siren, mast cable and spray lines on both gutters. Tank and pump shown as context in the hero only.
- `media/`: `hero.png` (1.75 m figure), `concept-blueprint.png`, `.pdf` and `.svg` (orthographic views at 1:100), `model.glb` and `viewer.html`, `exploded.png` with BOM callouts, `cutaway.png` (section through the front eave at a spray head), `flow.png` (water per 4 h event, all values marked as estimates). The hero, cutaway and exploded views are custom renders from the same model so the small kit parts read clearly against the house; temporary `media/_views*` folders are removed by the script.
- `bom/bom.csv`: 16 lines with indicative prices, numbered to match the exploded view; `bom/bom-notes.md` updated.
- `README.md`: hero image and links line before "## Problem"; problem, concept, key components and safety updated to match the precis. Pitch sentence unchanged.
- `docs/pdf/`: branded PDFs of the three controlled documents.
- `project.yaml`: unchanged. The pitch and problem still match the concept.

### Key results (estimates, to be checked at TRL 3)

| Quantity | Estimate | Requirement |
| --- | --- | --- |
| 100 cm² smouldering spot at 14 m | tens of kelvin of pixel rise | R1 met |
| 10 mm ember, 800 °C / 600 °C, at 8 m | about 5 K / about 3 K against a 5 K trigger | **R2 partly met** |
| Gutter coverage from one gable-end mast | 1.3 m to 13 m of each gutter | R3 met except 1.3 m per gutter |
| Water at farthest head after detection | about 55 s | R5 met |
| Net wetting at 30 km/h wind | about 3.8 mm/h (7.7 mm/h gross, 50 % drift assumed) | **R6 not met** (target 5 mm/h) |
| Steady flow; water per 4 h event | 4 L/min; about 960 L | R7 met, no margin |
| Battery need, 72 h armed plus 4 h spraying | about 64 Wh against about 69 Wh usable | R8 kit part met, thin margin; **not met by the kit alone** with a grid-powered pump |
| Mast bending stress at 120 km/h | about 25 MPa in a 40 x 2 mm aluminium tube | R10 wind met; thermal unverified |
| Kit parts cost | about $420 | **R13 not met** (budget $300, 40 % over) |

Requirements not met or at risk:

- **R6 (net wetting) not met:** wind drift is assumed at 50 %; the true figure is unknown and could be better or much worse.
- **R13 (cost) not met:** about $420 against $300.
- **R2 (single embers) partly met:** a 600 °C ember falls below the proposed 5 K threshold beyond about 5 m. Smouldering spots (R1) are easy to see; single cool embers are not.
- **R8 not met by the kit alone** where the pump needs grid power during an outage.
- **R10 thermal, R11 install time and false-trigger rate** are unverified.

### Proposed, awaiting Amish

Status update: items 1 to 9 were decided by Amish, 2026-09-25: go with recommendation (EGD-DDR-001, D1 to D9). Item 10 had no recommendation and stays proposed, awaiting Amish.

1. **Budget.** Parts are about $420 against `budget_usd: 300`. Options: (a) raise `budget_usd` to $425; (b) keep $300 by dropping to one thermal sensor and one zone (watches only one roof plane, about $340, still over); (c) keep $300 for a "sense and control" kit and cost the spray lines and valves as a separate zone kit (about $320 and $100). Recommendation: (a). `project.yaml` is unchanged.
2. **Sensing approach.** Two MLX90640-class thermal arrays (recommended) versus cheap near-infrared flame sensors (about $5, but cannot locate hot spots or reject sunlight) versus a single wide-angle 110 degree array (cheaper, but single embers become invisible beyond a few metres).
3. **Mast position.** Gable end at the ridge line, watching both roof planes (recommended), versus mid-eave on one side (simpler install, one roof plane only), versus two masts.
4. **Eave line material.** UV-stable polyethylene (in the cost) versus copper or galvanized steel eave runs (about $110 more, survives ember contact). Recommendation: metal on the eave runs, polyethylene only for the ground-level risers, if the budget allows.
5. **Water source for the first design case.** Tank with a pump on its own supply (recommended, protects hydrant pressure) versus mains connection.
6. **Pump power in an outage.** (a) Out of scope; homeowner provides a generator or gravity feed (current concept); (b) add a 12 V diaphragm pump and a larger battery (about 160 to 200 Wh more for 4 h of continuous pumping at 4 L/min, estimate); (c) power a 12 V pump from a portfolio SwapCell pack (about 468 Wh). Recommendation: (a) for TRL 2, with (b) or (c) studied at TRL 3. Using SwapCell is only an option here and is not assumed anywhere in the design.
7. **Arming thresholds.** Defaults of 30 km/h sustained or 50 km/h gusts with humidity at or below 20 % for 10 min, plus manual and remote arming. Recommendation: keep as adjustable defaults and review with a local fire agency.
8. **Fail-to-wet on sensor loss while armed** (recommended) versus fail-to-stop.
9. **Normally closed valves** (recommended, close on power loss) versus latching valves (lower energy, but stay open if the controller dies).
10. **First partner** for co-design and field input: a Firewise-style neighbourhood group, a county fire-safe council or a university WUI research group.

### Safety concerns

- False reassurance: people might stay behind or skip home hardening. Every document says EmberGuard does not replace evacuation or hardening.
- Work at height during installation and maintenance.
- Water and electricity: the kit is 12 V only; a mains pump must keep its own certified controls and ground-fault protection.
- LiFePO4 battery: fused, with BMS, inside the steel enclosure.
- Lightning: the mast is the highest point on the house and must be earthed.
- Community water pressure: automatic spraying from mains during a fire can reduce hydrant pressure; flow is capped at 4 L/min and a tank is preferred.

### Problems and gaps

- **Sources not re-verified.** The web search budget for this session was used up, and web fetches were not permitted, so no page could be opened. Sources in EGD-PRB-001 were cited from prior knowledge (DOIs for Caton et al. 2017, Hakes et al. 2017, Manzello et al. 2020, Syphard and Keeley 2019, NIST TN 1635 and TN 2135; home pages for CAL FIRE, CPUC, NFPA, Melexis and Frontline). Mitchell (2006) and AS 5414:2012 are cited without links. Every link and claim should be checked before the documents leave draft. No percentage for ember-caused ignitions is quoted for this reason.
- The detection figures rest on a simple radiometric estimate with no motion blur, smoke attenuation or lens transmission included.
- The legacy `cad/src/model.py` placeholder is untouched (TRL 3 work).

### Recommended next step

Review this note and the media, then decide items 1, 4 and 6. If approved, run `/advance-trl3` to check the radiometric detection estimate, spray drift and wetting, energy budget and mast wind load by calculation, and to build the parametric model and drawing sheet.

## Session 2026-09-25: TRL 3

Amish approved all recommendations across all batches on 2026-09-25 and said not to proceed to TRL 4. This session took EmberGuard from TRL 2 to TRL 3 and stopped.

### What was done

- `docs/decisions/0001-trl2-review-decisions.md` (EGD-DDR-001 v0.1): nine items decided by Amish (D1 to D9) and five left open (O1 to O5).
- `docs/04-calcs/01-sizing.md` (EGD-CAL-001 v0.1) with `docs/04-calcs/sizing.py` and `results.csv`: viewing geometry, radiometry, line fill, pressure, water, a droplet drift screening model, energy, pump power options (b) and (c), mast wind load, enclosure temperature, cost, and a status for every requirement. The script imports the model and reads the BOM and budget.
- `cad/src/model.py`: parametric build123d model (house reference, mast, head, sensors, ground unit, valves, spray lines) exporting `cad/step/` and `cad/stl/` files for the kit assembly, mast assembly, sensor head, ground unit and reference house.
- `cad/src/sheets.py` and `cad/drawings/EGD-DWG-001.svg`, `.pdf`, `.png`: general arrangement at Rev P1, 1:100 with 1:25 details of the mast and ground unit, marked "CONCEPT, NOT FOR FABRICATION" and "PRELIMINARY, NOT FOR FABRICATION". The concept sheet stays EGD-DWG-010.
- `bom/bom.csv`: 17 priced kit lines with supplier types (item 17, mast earthing kit, added) and one priced option row; `bom/bom-notes.md` updated.
- `cad/src/concept_media.py` now builds from the parametric model; all media in `media/` re-rendered and checked; no `media/_views*` folders remain.
- EGD-PRB-001, EGD-PRC-001 and EGD-REQ-001 raised to v0.3; `README.md` and `project.yaml` (`trl: 3`, `trl_target: 3`, `budget_usd: 425`, evidence list) updated. Pitch and problem lines unchanged (no rewording was recommended).

### Requirement status (EGD-CAL-001, Table 2)

Five not met, two at risk, one not verifiable at TRL 3, five met.

| ID | Status | Value |
| --- | --- | --- |
| R1 smouldering spot | **Not met** | Gutter interiors hidden; flat 100 cm² spot 2.8 K at 8.2 m against a 5 K trigger; a 100 x 50 mm hot debris face is seen to 26 m |
| R2 single ember | **Not met** | 600 °C ember 2.4 K at 8 m; reaches 5 K within 5.5 m |
| R3 watch both gutters | **Not met** | Roof edges in view 1.25 to 13.15 m from the mast; gutter interiors not visible from 228 mm above the ridge |
| R6 net wetting | **Not met** | Leeward eave 0.8 mm/h at 30 km/h (2.6 mm/h at half that); windward 7.4 mm/h; target 5 mm/h |
| R13 cost | **Not met** | $571 against $425 |
| R8 kit battery | At risk | 61.0 Wh needed; 69.1 Wh usable at 25 °C, 62.2 Wh at 0 °C, 55.3 Wh at end of life |
| R10 fire weather | At risk | Mast 27 MPa (factor 8.9), standoffs factor 3.5; enclosure about 71 °C in sun at 60 °C ambient |
| R11 installation | Not verifiable at TRL 3 | Install time not estimated |
| R4, R5, R7, R9, R12 | Met | Water at the farthest head in 55 s; 4 L/min and 965 L per event |

TRL 2 figures corrected in all documents: gutter coverage (now none), ember signal (2.4 K, not about 3 K), line lengths (17.7 and 21.3 m), water (965 L), net wetting, energy (61.0 Wh, not 64 Wh), mast stress (27 MPa) and cost ($571, not about $420).

### Decisions recorded (EGD-DDR-001)

Decided by Amish, 2026-09-25, going with each recommendation: D1 budget raised to $425; D2 two MLX90640 thermal arrays; D3 gable-end mast at the ridge line; D4 metal eave runs if the budget allows (it does not, so they are a $110 priced option); D5 tank with its own pump first; D6 pump power out of the kit's scope, with options (b) and (c) studied (R8 redefined); D7 adjustable arming defaults reviewed with a fire agency; D8 fail to wet on sensor loss; D9 normally closed valves.

### Still awaiting Amish

- **O1** First co-design partner (no recommendation; to be picked per area later).
- **O2** Cost: $571 against $425. Recommendation: raise the budget to about $575 until O3 and O4 are resolved. Decided by Amish, 2026-09-25: go with recommendation (EGD-DDR-002).
- **O3** Gutters hidden from the head. Recommendation: study two corner sensor pods looking along each gutter. Decided by Amish, 2026-09-25: go with recommendation (EGD-DDR-002).
- **O4** Leeward-eave wetting. Recommendation: run only the leeward zone, chosen from the wind vane. Decided by Amish, 2026-09-25: go with recommendation (EGD-DDR-002).
- **O5** A 2 K ember trigger (meets R2 for a centred ember) and a 10 Ah battery (about $13, clears R8). Recommendation: adopt both. Decided by Amish, 2026-09-25: go with recommendation (EGD-DDR-002).

### Safety concerns

- The gutter blind spot makes false reassurance worse: EmberGuard cannot see the place where embers most often lodge. The precis safety section now says so.
- Battery temperature: a dark steel enclosure in sun at 60 °C ambient reaches about 71 °C, above the LiFePO4 rating. The BOM specifies a light finish; a sun shade is not designed.
- Wall anchors carry about 710 N each at 120 km/h and must be checked for each wall; mast earthing (item 17) is now in the BOM.
- Work at height, the 12 V only rule with a dry contact to the pump, hydrant pressure and evacuation notes are unchanged.

### Citations

Checked on 2026-09-25 with web search and DOI records: Caton et al. 2017, Hakes et al. 2017, Syphard and Keeley 2019, NIST TN 1635 and NIST TN 2135 (titles, authors, years match). Manzello et al. 2020, Mitchell (2006, *Fire Safety Journal* 41, now linked), AS 5414-2012 (now linked) and the MLX90640 datasheet (18 mA typical, NETD 0.1 K at 1 Hz, used in EGD-CAL-001) were found by title. Not re-checked: the CAL FIRE, CPUC, NFPA and Frontline home pages and the NFPA 1140 statement.

### TRL 4 material

None found. `build-log/README.md` is the scaffold file and was not changed. No test, build or firmware work was started.

### Recommended next step

TRL 4 is on hold by Amish's instruction. The next step is a decision on O2 to O5, then a second TRL 3 revision (still TRL 3) that models the corner sensor pods or another fix for the gutter blind spot, re-runs EGD-CAL-001, and re-prices the kit. For reference only, TRL 4 would need: a heated-target and ember trial with the chosen sensor, recorded thermal video for false-trigger rates, a spray trial in wind on a roof-edge mock-up, a battery and enclosure heat test, a TST report with `environment: lab`, and build-log entries.

## Session 2026-09-25: recommendations accepted

Amish wrote on 2026-09-25: "i accept all your recommendations, go with them across all repos." Every open item with a recommendation is now decided in favour of it and recorded in `docs/decisions/0002-recommendations-accepted.md` (EGD-DDR-002 v0.1). EmberGuard stays at `trl: 3`, `trl_target: 3`.

### Decisions applied and what changed

| Item | Decision | Before | After |
| --- | --- | --- | --- |
| O2 Budget | Raise `budget_usd` | $425 | $575 (kit now $605, R13 still not met, 5 % over) |
| O3 Gutter blind spot | Thermal sensors in two gutter-corner pods, 200 mm beyond each gutter end and 500 mm above the lip, looking along the gutter | Ridge-line head saw gutter debris at 0 of 130 stations | Open gutter in view 1.25 to 12.95 m at 118 of 130 stations; R3 met |
| O4 Leeward wetting | Leeward zone only above 2 m/s cross-eave wind | Leeward eave 0.8 mm/h at 8.3 m/s, 2.6 mm/h at 4.2 m/s | 1.5 mm/h and 5.1 mm/h; windward eave dry until a windward detection; R6 still not met |
| O5 Trigger | Persistent-spot trigger lowered | 5 K; 600 °C ember detected to 5.5 m | 2 K; 8.8 m centred, 4.4 m on a pixel corner; R2 at risk |
| O5 Battery | 12.8 V LiFePO4 pack enlarged | 6 Ah, 55.3 Wh usable at end of life against 61.0 Wh | 10 Ah, 92.2 Wh against 67.5 Wh; R8 met |

Files changed: `project.yaml` (`budget_usd` 575); `README.md` (budget, concept, key components, and new sections "Concept rationale", "Burning platform", "Where it could be used" and "What sparked the idea"); EGD-PRB-001 v0.4, EGD-PRC-001 v0.4, EGD-REQ-001 v0.4, EGD-CAL-001 v0.2, EGD-DDR-001 v0.2, new EGD-DDR-002 v0.1; `bom/bom.csv` (items 2, 3, 8, 13; total $571 to $605) and `bom/bom-notes.md`; `cad/src/model.py` (pods replace the head; 10 Ah battery; pod cables) with STEP and STL re-exported (`sensor-head` replaced by `sensor-pod`); `docs/04-calcs/sizing.py` (section A rewritten with gutter end cap and hanger-strap checks; 2 K trigger; leeward-only rule; pod-node energy; mast without head) and `results.csv`; `cad/src/sheets.py` and EGD-DWG-001 at Rev P2; `cad/src/concept_media.py` and all of `media/` re-rendered (hero, blueprint, exploded view with the front pod, flow diagram for the leeward-only case); PDFs in `docs/pdf/` rebuilt. The old ridge-line head is withdrawn from all current documents.

### Requirement status (EGD-CAL-001 v0.2)

Two not met, three at risk, one not verifiable at TRL 3, seven met (was five not met, two at risk, five met).

| ID | Status | Value |
| --- | --- | --- |
| R6 wetting | **Not met** | Leeward eave 1.5 mm/h at 8.3 m/s, 5.1 mm/h at 4.2 m/s; target 5 mm/h |
| R13 cost | **Not met** | $605 against $575 |
| R1 smouldering spot | At risk | Hot debris face seen to 41 m; flat spot to 12.1 m; hanger straps hide debris 42 mm below the lip at 83 of 118 stations, all beyond 7.8 m |
| R2 single ember | At risk | 8.8 m centred, 4.4 m on a pixel corner; 2 K false-trigger rate unknown |
| R10 fire weather | At risk | Enclosure about 71 °C in sun at 60 °C ambient; pods exposed at the gutters; mast 14 MPa (factor 16.6) |
| R11 installation | Not verifiable at TRL 3 | Install time not estimated |
| R3, R4, R5, R7, R8, R9, R12 | Met | Gutters in view; 55 s to water; 965 L per event; 115 Wh usable against 67.5 Wh |

### Still awaiting Amish

- **O1** First co-design partner (no recommendation; to be picked per area later).
- **N1** Cost of the revised kit, $605 against $575. Recommendation: find about $30 of savings (lighter mast, unbranded breakouts), with a budget of about $610 as the fallback. **Decided by Amish, 2026-09-26: budget set to $605 to cover the priced BOM; see "Session 2026-09-26: budget approved".**
- **N2** Leeward wetting at the design wind. Recommendation: study coarser, lower-angle droplets or a second leeward row of heads on paper at the next TRL 3 revision.
- **N3** Hanger-strap shadow. Recommendation: study pods about 1 m above the lip on paper, and list gutter guards as an installation precondition.
- **N4** Pitch wording. The pitch still says "Roof-edge sensor mast". Recommendation: "Gutter-corner thermal sensors and a weather mast that detect ember showers and trigger a gutter and eave sprinkler zone." Pitch unchanged until Amish decides.

### Cross-repo actions

None. Pump option (c) still only studies a SwapCell pack; nothing in EmberGuard's baseline depends on another repo.

### Write-up sections and inspiration

`README.md` now has "Concept rationale", "Burning platform" (UNEP 2022 projections, Radeloff et al. 2018 WUI growth, NIST on the Camp Fire, the Royal Commission on Black Summer), "Where it could be used" (five industries; United States, Canada, Australia, Chile, South Africa and Mediterranean Europe) and "What sparked the idea". The inspiration point is the CSIRO survey of about 1,150 houses after the Ash Wednesday fires of 16 February 1983 (*Ecos* 43, 1985), which found that burning debris lodging in gaps, at ridges and at gutters most often set houses alight, and that people present could save houses by attacking small fires early with a few buckets of water. EGD-PRB-001 needed no change to its account of the idea's origin. All sources were opened on 2026-09-25 except the Radeloff et al. paper, whose figures were checked through a PNNL summary of it; the Chile figure comes from a UN Connecting Business initiative page citing ReliefWeb.

### Safety concerns

- The pods sit at the gutter ends, where embers land and radiant heat is higher; their survival time is unknown. Fail to wet on sensor loss (D8) covers a lost pod.
- Hanger straps hide deep debris far from the pods, so gutters must still be kept clean; the precis safety note now says so.
- In wind the windward eave is not sprayed until a detection on that side.
- Pod brackets hang beyond the gutter ends and must be clamped to sound fascia; their wind load is not yet checked.
- Battery enclosure temperature, work at height, 12 V only, earthing and hydrant pressure notes are unchanged.

### TRL 4

TRL 4 remains on hold by Amish's instruction. Nothing past TRL 3 was started: no trials, thermal video, spray tests, PCB, firmware beyond the arming and spray rules described in the precis, or purchasing.

### Recommended next step

A decision on N1 to N4, then a further TRL 3 revision that studies higher pods and a leeward head arrangement on paper, checks the pod brackets for wind, and re-prices the kit.

## Session 2026-09-26: sources strengthened

- "Where it could be used", country table: the uncited "Mediterranean Europe" row is replaced by "Greece (Mediterranean Europe)", citing the European Parliament motion for a resolution B8-0391/2018 on the July 2018 Mati fire (at least 98 dead; thousands of houses and vehicles destroyed), with NOAA Climate.gov's event report alongside. Old source: none. Both links were opened on 2026-09-26.
- All other rows, "Concept rationale", "Burning platform" and "What sparked the idea" already rested on primary or reputable secondary sources and are unchanged. No budget change. No controlled doc changed.

## Session 2026-09-26: budget approved

Amish wrote, in chat on 2026-09-26: "i approve all the budget items." N1 is decided: budget set to $605 to cover the priced BOM (EGD-DDR-002 v0.2).

- `project.yaml` `budget_usd` $575 to $605; README budget and cost lines updated.
- R13 target $575 to $605; status **not met to met**, with no margin ($605 kit; the $110 metal eave option stays outside the kit).
- Requirement counts (EGD-CAL-001 v0.3): one not met (R6), three at risk, one not verifiable, eight met.
- Documents: EGD-PRB-001 v0.5, EGD-PRC-001 v0.5, EGD-REQ-001 v0.5, EGD-CAL-001 v0.3 (script re-run, `results.csv` regenerated), EGD-DDR-002 v0.2; `bom/bom-notes.md`; blueprint key figure in `cad/src/concept_media.py` and `media/` regenerated; PDFs rebuilt.

## Session 2026-09-26: product appearance model and photoreal renders

Amish chose this repo for the first batch of product renders on 2026-09-26.

### What was done

- `cad/src/product_model.py` (new): `product_parts()` returns 78 parts, each with a colour, a render material, a BOM line, a group and an explode offset, plus `TITLE` and `RENDER_VIEWS` (hero, exploded and a sensor pod detail view). It imports `PARAMS`, `derived()`, `sensor_axes()` and `house_parts()` from `model.py`; every size, the pod position and aim, the gutter and spray-line geometry and every interface come from them. Parts by group: shell 16 (the front sensor pod, its thermal sensor, hood and bracket), internal 2 (pod node board and chips), accessory 55 (mast and weather head, humidity shield, solar panel, ground unit and contents, valves, spray line, cables) and context 5. The mast and the rest of the kit are in the accessory group so that the detail view (shell and internal) shows the pod alone.
- It adds, as appearance detail only:
  - Sensor pod (items 2 and 3): filleted die-cast body with side ribs and a lens bezel, a back cover on a parting line with four screws, a lit green status light, a label with an accent band, the stainless hood as a bent sheet with drip flanges on four spacers, the black sensor snout with a dark germanium lens along the `sensor_axes()` aim, a cable gland, the post and arm with a filleted gutter-end clamp and two bolts.
  - Weather head and mast (items 1, 4, 5 and 9): mast-top adapter, stub, tee and crossarm; three-cup anemometer with hemispherical cups; wind vane with a shaped tail fin, nose weight and accent; mast end cap; galvanized standoffs with filleted wall plates, pipe flanges, four anchors each and split clamp collars with bolts; five-plate radiation shield on three rods with its probe and arm; solar panel with an aluminium frame, dark cells, busbars, junction box, arm and clamp.
  - Ground unit (items 6, 7, 8, 12 and 15): light grey steel body and door with a seam, hinges, four screws, a teal name plate and a warning label; key switch, piezo siren and a lit green status beacon; four bottom cable glands; controller board, battery with label and relay inside.
  - Valves and transducer (items 10 and 11) on a brass manifold; black polyethylene spray line (item 14) on the gutter lip with three lip clips, a micro-sprinkler head with a teal spinner cap and the riser elbow; mast cable and pod cable (item 13) with cable ties and the silicone heat sleeve at the pod.
  - Context (grey, no BOM number): a compact corner of the reference house at the east end of the front eave, with lap-siding lines, the roof overhang with shingle courses, the fascia, the gutter with an end cap and two hangers.
- `README.md`: hero image now `media/render-hero.png`; exploded render link added. The renders themselves are produced later by the orchestrator.
- Self-check previews (matplotlib) were reviewed for the hero, exploded and detail views.

### Differences from model.py (Proposed, awaiting Amish)

1. **Render layout.** For a compact product render the mast and everything on it is drawn at y = -3.60 m (installed on the ridge line, y = 0) and 1.15 m lower, so that both standoffs still meet the gable wall below the roof next to the front gutter corner; its 700 mm offset from the wall, its length and every height on it relative to the mast are unchanged. The ground unit is drawn at y = -3.33 m (installed -1.80 m) at its `model.py` height, the valve manifold just below it at 0.79 m (installed 0.45 m) and 120 mm in from the riser line, and only the east 0.9 m of the front spray line and the top 420 mm of its riser are shown. The front pod, gutter corner and spray line are at their `model.py` positions. Recommendation: accept as a render-only layout and say so in figure captions ("not the installed spacing").
2. **Sensor aim.** `model.py` draws the lens barrel along -X; the appearance model draws the snout along the `sensor_axes()` aim (10 degrees toward the house, 5 degrees down), which is the decided aim. Recommendation: draw the barrel on the aim in `model.py` at the next model session.
3. **Hood.** `model.py` shows the hood as a 6 mm slab on the pod top; the appearance model shows the BOM's bent 0.8 mm class stainless sheet (drawn 1.5 mm) with drip flanges on four spacers, inside the same 150 x 130 mm envelope, leaving an air gap as a heat shield. Recommendation: adopt the spaced hood in `model.py` and EGD-DWG-001.
4. **Enclosure colour and door.** `model.py` colours the ground enclosure dark teal; the appearance model uses the light grey finish the BOM and EGD-CAL-001 section F call for (R10), with a hinged door on the +X face. Recommendation: change the `model.py` colour to light grey at the next media refresh.
5. **Spray line colour.** `model.py` draws the spray line blue for legibility; the appearance model shows black UV-stable polyethylene, as bought. Recommendation: keep `model.py` as it is.
6. **Cable routes.** The mast and pod cables are drawn along the mast, under the lower standoff, down the house corner and into bottom glands on the ground unit, following the render layout. Recommendation: accept as appearance only; installers set the real routes.

### Scope

This is an appearance model only: no tolerances, no fabrication detail, no PCB layout. `trl` stays 3 and TRL 4 remains on hold. No BOM, model, drawing or document other than `README.md` and this note was changed.

## Session 2026-09-27: kit 1.5.0 and image quality

- Kit 1.5.0 synced: STANDARDS v1.5 (sections 12 to 15: product renders, storefront images and image quality, public release, authorship and signing), `.kit/cards.py`, `.kit/image_qc.py`, `.kit/release_gate.py`, issue templates, and the `/render-product` and `/release` commands. `CLAUDE.md` now matches `.kit/CLAUDE.md`.
- Every `media/render-*.png` recaptioned from its original render with the new layout: the title, concept label and repository sit in a band above the render and the view note in a band below it, each line wrapped to the image width, so no text overlaps other text or the render or runs off the image. `media/card.png` and `media/social-preview.png` regenerated with the same rules.
- `python .kit/image_qc.py` and `python .kit/release_gate.py` pass. trl stays 3.

## Session 2026-10-01: design for construction and prototype build plan (kit 1.7.0)

Amish approved the build plan format on 2026-09-30 and asked for it across all repos, with outstanding decisions kept in a separate design decisions register. His instruction for this work: "If you are realising that the design cannot be built as per concept - fix the design assumptions to match and be physically feasible as you draw the illustrations." EmberGuard stays at `trl: 3`; nothing was built or tested.

### What was done

- Kit 1.7.0 installed (`.kit/`, `.claude/commands/`); `CLAUDE.md` matches `.kit/CLAUDE.md`.
- `cad/src/model.py` rewritten as a constructable model: 66 named parts with fixings, `build_components()`, and `python cad/src/model.py --check`, which runs 103 constructability checks (contacts, clearances and the sensors' field of view); all pass. `build_parts()`, `PARAMS`, `derived()`, `sensor_axes()` and `house_parts()` are kept for the calculations, drawing and media.
- `docs/decisions/0003-design-for-construction.md` (EGD-DDR-003 v0.1, Draft): every change, made under Amish's 2026-09-30 instruction to make the design physically buildable; open for his review.
- `docs/05-build-plan.md` (EGD-BLD-001 v0.1) and `docs/06-design-decisions.md` (EGD-DEC-001 v0.1).
- `cad/src/build_plan_media.py`: overview, 13 making sketches (`cad/drawings/EGD-DWG-101` to `113`), 12 joint close-ups, 17 assembly step pictures and a wiring diagram in `docs/05-build-plan/`.
- `bom/bom.csv` and `bom/bom-notes.md`; `docs/04-calcs/sizing.py` (new [E5], pod arm and cleat) and `results.csv`; EGD-CAL-001 v0.4, EGD-REQ-001 v0.6, EGD-PRC-001 v0.6.
- STEP and STL re-exported; EGD-DWG-001 at Rev P4; concept media regenerated (`cad/src/concept_media.py` now falls back to the edge-by-edge projection of `sheets.py` when the kit's `project_views` meets a degenerate edge, and exports `media/model.glb` at coarser tessellation, 3.2 MB instead of about 17 MB); `project.yaml` (`design_state: constructable`, new evidence); `README.md` (links line and "Building the prototype").

### Design changes made for construction (EGD-DDR-003)

1. Standoffs pass beside the mast and join it by crossover plates and U-bolts; slip-on flanges on aluminium wall plates (no welding, no holes in the mast or pipe).
2. Mast cable inside the mast tube, out through a grommeted end cap and under the lower standoff.
3. Solar panel turned to face the equator side (the model had it facing away) and fixed on a pole-mount tilt bracket.
4. Humidity shield on a centre rod and mast clamp; wind sensors on a sleeve over the mast top.
5. Pod mount: a verge cleat screwed to the end of the roof overhang, a bent 40 x 6 mm flat bar arm and a pod plate with a pivot and slot for the aim, replacing a clamp block buried in the gutter end.
6. Thermal sensor in a 9.5 mm window in the pod wall with a short lens hood, replacing a 70 mm sighting tube that would have cut the 55 x 35 degree view to about 23 degrees across.
7. Pod hood on four 15 mm spacers with drip flanges (adopts item 3 of the 2026-09-26 render note).
8. Pod node board on standoffs; pod cable through an M16 gland.
9. Ground enclosure on wall lugs, cables through bottom glands, battery strapped on the floor, boards on the gear plate.
10. Valves each on their own tee under a manifold on a wall-mounted valve board (in the concept a closed valve A would have shut off valve B).
11. Risers up the gable wall corner, out under the gutter and up in front of it; eave line in 24 lip clips, 20 mm in front of the lip. Lines 17.5 m and 21.1 m; fill 54 s.
12. Pod cables along the arms, under the verge and down the wall; mast earthing clamp, conductor and rod modelled.

### Key results

- Requirement status (EGD-CAL-001 v0.4): one not met (**R6** leeward wetting), one over its value-engineering target (**R13** cost), three at risk (R1, R2, R10), one not verifiable (R11), seven met. R13 moved from met to over the target: the kit is now **$689 against the $605 value-engineering target**, USD 84 over.
- Pod arm at 120 km/h: about 8 MPa, factor 19; about 70 N pull per coach screw [E5]. Mast and anchors unchanged [E3], [E4].
- Water at the farthest head 54 s (was 55 s); supply about 2.3 bar.

### Proposed, awaiting Amish

All open items are indexed in `docs/06-design-decisions.md`. New in this session: accept EGD-DDR-003; a window in front of the sensor (recommend none for the prototype); a fascia-face pod bracket for houses without a timber verge (recommend once partner houses are known). Still open from earlier: enclosure sun shade, N2, N3, N4, O1, render items 1 and 5. The budget is not a decision: `budget_usd` stays $605 as a value-engineering target, and the savings worth trying are in the register's Value engineering section (2026-10-01 wording pass).

### Safety concerns

- Fitting the pods and risers is ladder work at the roof edge; the plan has safety stops for height, drilling, battery, water, the pump contact and leaving the kit armed.
- The sensor can now faces the weather in its window, sealed by an O-ring; ash and water on the lens are untested (register item 2).
- The battery enclosure still has no sun shade (R10).

### Stale media (made on Amish's Mac, not regenerated here)

The design changed visibly, so `media/render-hero.png`, `media/render-exploded.png`, `media/render-detail.png`, `media/card.png` and `media/social-preview.png`, and the appearance model `cad/src/product_model.py`, are stale: they show the concept pod bracket and long sighting tube, the free-standing riser, the inline valves and the panel facing away from the equator.

### Recommended next step

Amish reviews EGD-DDR-003 and the register (item 1 first). Then refresh the product renders on the Mac. TRL 4 stays on hold.

## Session 2026-10-02: open decisions decided

On 2026-10-02 Amish approved every recommendation written for the open decisions: "i approve your recommendations for all 555 open decisions." Nothing was built or tested; TRL 4 remains on hold.

### Decisions recorded

12 decisions moved from "Open decisions" to "Decisions made" in the design decisions register, dated 2026-10-02. Design for construction (EGD-DDR-003) accepted with its items A2 and A3; enclosure siting, finish and a 45 °C charge limit; leeward wetting and higher pods to be studied on paper with R1 and R6 unchanged; new pitch; a Firewise USA group named as the first partner to approach; render, media, third-sensor and data-sharing choices.

### Documents changed

- `docs/01-problem.md` (EGD-PRB-001 v0.6)
- `docs/02-concept.md` (EGD-PRC-001 v0.8)
- `docs/03-requirements.md` (EGD-REQ-001 v0.8)
- `docs/05-build-plan.md` (EGD-BLD-001 v0.3)
- `docs/06-design-decisions.md` (EGD-DEC-001 v0.3)
- `docs/decisions/0001-trl2-review-decisions.md` (EGD-DDR-001 v0.3)
- `docs/decisions/0002-recommendations-accepted.md` (EGD-DDR-002 v0.3)
- `docs/decisions/0003-design-for-construction.md` (EGD-DDR-003 v0.3)
- `project.yaml` (not a controlled document)
- `README.md` (not a controlled document)
- `bom/bom-notes.md` (not a controlled document)
- `docs/pdf/`: every controlled document re-rendered.

### Follow-up actions to carry approved decisions into the design

The model, drawings, build plan pictures, BOM quantities and prices, and calculations were not changed in this session. These actions carry the approved decisions into them:

1. Decision 2 (docs): TRL 4 test plan (when TRL 4 starts): include an ash-fouled lens case in the heated-target and ash trials.
2. Decision 3 (drawings): Draw a fascia-face pod bracket once the partner's houses are known (model, making sketch, build plan pictures).
3. Decision 4 (model): Design the folded white sheet shade for the ground enclosure at the next revision (model, making sketch, build plan pictures, BOM line).
4. Decision 4 (bom): BOM line 9: specify a charge controller that stops charging above 45 °C; BOM line 7: note the shadiest-wall siting; add the shade when designed.
5. Decision 4 (calcs): EGD-CAL-001 section F: re-run the enclosure temperature with the light finish and the shade once designed.
6. Decision 5 (calcs): EGD-CAL-001 section C: study larger, lower-angle droplets and a second leeward row of heads on paper at the next revision.
7. Decision 6 (calcs): EGD-CAL-001: study pods about 1 m above the gutter lip (view over the hanger straps, arm wind load [E5], ember exposure); change the model only if the study supports it.
8. Decision 6 (docs): Build plan: add gutter guards to the site checks or installation notes where deep debris collects.
9. Decision 7 (pictures): Regenerate media/card.png and media/social-preview.png if they carry the old pitch text.
10. Decision 9 (pictures): At the next render session on Amish's Mac: redraw the product renders to the constructable design (pod bracket, lens hood, riser, panel facing the equator) and add captions saying the mast and ground unit are drawn closer than installed.

### Points found in the review

Raised when the recommendations were written (2026-10-01) and not yet acted on:

- The decisions-made table has no row for EGD-DDR-003 (design for construction, 2026-09-30), unlike the other registers.
- The kit is USD 689 against the USD 605 value-engineering target (14 % over); the listed savings total only about USD 35.
- The panel facing in P3 ("south, the equator side") holds only in the northern hemisphere; the build plan should say "toward the equator".
- Renders still show the concept pod bracket, long sighting tube, free-standing riser and a panel facing the house.

## Session 2026-10-02: approved follow-ups carried out

Amish approved carrying out every follow-up that needs CAD, drawing, picture, BOM or calculation work. Nothing was built or tested; TRL 4 remains on hold. No decision was made in this session; items marked "Proposed, awaiting Amish" are for him.

### Follow-ups (numbered as in the 2026-10-02 list above)

1. Decision 2, TRL 4 test plan with an ash-fouled lens case: not done, TRL 4 work (on hold).
2. Decision 3, fascia-face pod bracket: not done, waits for the partner's houses to be known.
3. Decision 4, sun shade in the model: done. New BOM line 18 (folded white 1 mm sheet on two flat-bar arms), 8 new constructability checks (111 of 111 pass), STEP and STL regenerated, making sketch EGD-DWG-114, overview picture, build plan section 3.15 and step 18.
4. Decision 4, BOM: done. Line 9 now has a battery temperature probe that stops charging above 45 °C ($38 to $42); line 7 notes the shadiest-wall siting; line 18 added at $14, each with a price basis.
5. Decision 4, enclosure temperature: done (EGD-CAL-001 [F5], [F6]): 67 °C with the light finish alone, 63 °C with the shade at 60 °C ambient; sun shade wind check [E7]. R10 stays at risk.
6. Decision 5, leeward wetting study: done on paper ([C11] to [C14]); model unchanged. Coarser droplets give 4.6 mm/h at 8.3 m/s (target 5, R6 still not met); lower angles wet only the roof edge; a second leeward row needs 1,920 L per event. Proposed, awaiting Amish: whether to try a coarser-spray head at TRL 4.
7. Decision 6, pods 1 m above the lip: done on paper ([A8], [E6]); model unchanged because the study does not support the change (first 1.2 m of each gutter lost, arm load about three times higher).
8. Decision 6, gutter guards: done, site notes added to the build plan section 4.
9. Decision 7, card.png and social-preview.png: not done, made on Amish's Mac with the renders.
10. Decision 9, product renders: appearance model `cad/src/product_model.py` brought to the constructable design (pod plate, arm and verge cleat, lens hood, flanges, crossover plates and U-bolts, panel facing the equator on its tilt rail, valve board with valves on their own tees, riser up the gable corner, sun shade); render scenes exported to `/home/claude/renders/emberguard`. Photoreal renders and captions (mast and ground unit drawn closer than installed) are made on the Mac.

### Documents changed and new versions

- `docs/04-calcs/01-sizing.md` EGD-CAL-001 v0.6; `docs/04-calcs/sizing.py` and `results.csv`
- `docs/02-concept.md` EGD-PRC-001 v0.9; `docs/03-requirements.md` EGD-REQ-001 v0.9
- `docs/05-build-plan.md` EGD-BLD-001 v0.4; `docs/06-design-decisions.md` EGD-DEC-001 v0.4
- `docs/decisions/0003-design-for-construction.md` EGD-DDR-003 v0.4 (render note only)
- `bom/bom.csv`, `bom/bom-notes.md`, `README.md`, `cad/src/*.py`, STEP and STL, drawing EGD-DWG-001 Rev P5, EGD-DWG-114, concept media, build plan pictures; `docs/pdf/` re-rendered.

### Key results

Value-engineering target: USD 605. Estimated cost of the constructable design: USD 707 (USD 102 over the target). Requirement statuses are unchanged (R6 not met, R13 over target, R1, R2 and R10 at risk, R11 not verifiable, six met). The BOM has no mass figure; none was added.

### Cross-repo actions

None for this repo. The partner outreach (Firewise USA group, Texas A&M Forest Service) is Amish's.

### Safety concerns

The enclosure still exceeds the battery's 60 °C discharge limit at 60 °C ambient even with the shade; charging stops above 45 °C by design. The shade's wall screws see about 320 N in a 120 km/h gust.

### Recommended next step

Amish decides on the coarser-spray head option; then refresh the photoreal renders on the Mac. TRL 4 stays on hold.

## 2026-10-02: photoreal renders redone on the constructable design

Rendered with Blender Cycles on Amish's Mac from the updated appearance model; captioned with `.kit/photo_caption.py`; `media/card.png` and `media/social-preview.png` regenerated with `.kit/cards.py`. Views: hero, exploded, detail. image_qc passes. Appearance deviations are those logged above as proposed, awaiting Amish.

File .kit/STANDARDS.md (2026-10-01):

---
doc_id: OHP-STD-001
title: Documentation and drawing standard
project: Open Hardware Portfolio
doc_type: Standard
version: "1.7"
status: Released
date: 2026-09-30
author: Amish Chadha
license: CC-BY-SA-4.0
revisions:
  - version: "1.0"
    date: 2026-09-24
    author: Amish Chadha
    change: First release of the standard
  - version: "1.1"
    date: 2026-09-24
    author: Amish Chadha
    change: Adopt Technology Readiness Levels (section 9) for project maturity
  - version: "1.2"
    date: 2026-09-24
    author: Amish Chadha
    change: Portfolio phase cap (section 10), concept media standard (section 11), CLAUDE.md guardrails
  - version: "1.3"
    date: 2026-09-24
    author: Amish Chadha
    change: Scale figure, interactive 3D viewer and flow diagrams added to concept media; session slash commands
  - version: "1.4"
    date: 2026-09-26
    author: Amish Chadha
    change: Every sheet and render names the project and its GitHub repository; overall dimensions, ISO centre lines and 300 dpi PNG on sheets; titles name the device and view labels state the viewing direction; optional photoreal renders with Blender
  - version: "1.5"
    date: 2026-09-27
    author: Amish Chadha
    change: Product renders (section 12), storefront images and image quality check (section 13), public release and release gate (section 14), authorship, citation and commit signing (section 15)
  - version: "1.6"
    date: 2026-09-29
    author: Amish Chadha
    change: Licensing metadata with REUSE (section 16), Zenodo DOI and Software Heritage archiving (section 17), release gate checks REUSE and a single CITATION.cff license, archive.py
  - version: "1.7"
    date: 2026-09-30
    author: Amish Chadha
    change: Concept and constructable design states; design decisions register (DEC) kept apart from the build plan; prototype build plan (BLD, section 18) with pictures by component is required TRL 3 evidence; every repo targets TRL 3 during the populate phase; build_views.py; /to-trl3 and /build-plan commands
---

# Documentation and drawing standard

Every project in the portfolio uses this standard, so that each precis, write-up and sketch looks the same and carries its own version history. The standard ships as a kit in each repo's `.kit/` folder. The kit version is in `.kit/KIT_VERSION`.

## 1. Document types and IDs

Every controlled document has a unique ID in the form `PRJ-TYP-NNN`.

- `PRJ` is the three-letter project code listed in section 7.
- `TYP` is the document type code from the table below.
- `NNN` is a sequence number within that project and type, starting at 001.

| Code | Type | Typical file |
| --- | --- | --- |
| PRC | Design precis | `docs/02-concept.md` |
| PRB | Problem statement | `docs/01-problem.md` |
| REQ | Requirements | `docs/03-requirements.md` |
| CAL | Calculation or sizing note | `docs/04-calcs/*.md` |
| DDR | Design decision record | `docs/decisions/*.md` |
| BOM | Bill of materials | `bom/bom.csv` |
| DWG | Drawing or sketch sheet | `cad/drawings/*.svg` |
| BLD | Prototype build plan (section 18) | `docs/05-build-plan.md` |
| DEC | Design decisions register (section 18) | `docs/06-design-decisions.md` |
| TST | Test plan or test report (front matter adds `environment: lab` or `relevant`) | `docs/05-tests/*.md` |

Example: `TBK-PRC-001` is the ThermaBrick design precis.

## 2. Revision scheme

| Artifact | While in draft | When released | Change after release |
| --- | --- | --- | --- |
| Documents | 0.1, 0.2, 0.3 ... | 1.0 | 1.1 for minor edits, 2.0 for a design change |
| Drawings | Rev P1, P2 ... (preliminary) | Rev A | Rev B, C ... |

- Every change to a controlled document adds a row to its revision history before the commit.
- The `version` field in front matter always equals the newest row in `revisions`. The renderer rejects a document where they differ.
- Status is one of `Draft`, `In review`, `Released` or `Superseded`. Draft and In review documents print with a status band on every page.
- Every release is tagged in Git as `<doc_id>/v<version>`, for example `TBK-PRC-001/v1.0`. Drawings are tagged `TBK-DWG-001/revA`.
- Git history is the full audit trail. The in-document revision table is the human-readable summary.

## 3. Document front matter

Every Markdown document under version control starts with this block:

```yaml
---
doc_id: TBK-PRC-001
title: ThermaBrick design precis
project: ThermaBrick
doc_type: Precis
version: "0.1"
status: Draft
date: 2026-09-24
author: Amish Chadha
license: CERN-OHL-S-2.0
revisions:
  - version: "0.1"
    date: 2026-09-24
    author: Amish Chadha
    change: Initial draft
---
```

Quote version numbers so YAML keeps `1.0` as text instead of turning it into a number. List revisions newest last.

## 4. Writing style

- Chicago Manual of Style.
- No em dashes. Restructure the sentence instead.
- Lead each section with its conclusion, then support it.
- SI units throughout, in the form `12 kW`, `450 °C`, `3.2 m`. Imperial values may follow in parentheses.
- Number every figure and table ("Figure 2", "Table 1") and give each a caption.
- State every assumption in the calculation that depends on it.
- Put safety notes in a blockquote starting with **Safety:**.

## 5. Visual identity

| Element | Specification |
| --- | --- |
| Typeface | IBM Plex Sans for text, IBM Plex Mono for code and values (SIL Open Font License, bundled in `.kit/fonts`) |
| Ink | `#111827` |
| Secondary text | `#4B5563` |
| Rules and grid | `#D1D5DB` |
| Accent (one only) | `#0F766E` teal |
| Document page | US Letter, 20 mm margins |
| Drawing sheet | ANSI B landscape (431.8 x 279.4 mm) |
| Footer | Document ID, version, status, license and designmolecule.com on every page |

## 6. Drawing and sketch conventions

- Units are millimeters unless the title block says otherwise.
- Third-angle projection, marked with the symbol in the title block.
- Line weights: visible outlines 0.5 mm, hidden lines 0.25 mm dashed, center lines 0.18 mm chain.
- The title block contains the project, title, drawing number, revision, scale, units, projection, sheet, author, date, material or notes, and license.
- Every sheet and every render names the project and its GitHub repository (from `repo:` in `project.yaml`), at the top of the sheet and in the title block, so a printed or forwarded sheet is never anonymous.
- The drawing title names the device, not only the drawing type (for example "Handheld near-infrared resin scanner: general arrangement").
- Every view label states its scale and viewing direction (for example "Scale 1:1; side elevation looking along +Y"), and every isometric or render states where it is seen from.
- Orthographic views generated with `add_ortho` carry overall dimensions (length and depth on the top view, height on the front view) and ISO 128 centre lines on cylinders; hidden lines are dashed. Tolerances are not shown before TRL 4.
- Sheets are exported as SVG, PDF and a 300 dpi PNG.
- The revision table in the top right of the sheet lists every revision.
- Concept sketches use the same sheet and title block and carry the label "CONCEPT, NOT FOR FABRICATION".
- Geometry comes from `cad/src/*.py` (build123d). Sheets are generated by `.kit/drawing.py` and never edited by hand.

## 7. Project codes

| Code | Project | Code | Project | Code | Project |
| --- | --- | --- | --- | --- | --- |
| TBK | ThermaBrick | PCF | PicoFlow | HLT | HelioLite |
| CCB | CharCube | DRN | DustRunner | TRT | TremorTrace |
| STC | StepCue | FXH | FlexHand | CPD | ColdPod |
| SCL | SunClave | STR | SteamRoot | GGD | GrainGuard |
| SDL | SeedLine | ZBX | ZeerBox | RMS | RootMesh |
| DWD | DewDrive | SSK | StillStack | PPR | PotPress |
| WWT | WaterWatch | LMF | LumaFlow | FCL | FieldCell |
| CNP | ConePro | CVC | CulvertCrawl | EGD | EmberGuard |
| SNF | SnapFrame | CGM | CargoMule | SCM | StepClimber |
| SWC | SwapCell | PLP | PalletPilot | FTK | FlatTrike |
| WWK | WaterWalker | GRR | GrowRider | SSP | SunSpoke |
| SGN | StepGen | PBX | PowerBox | WML | WasteWise-ml |
| WSC | WasteWise Scan | RFE | ReflowEconomy | | |
| OHP | Portfolio-wide | | | | |

## 8. Build and publish

- `python .kit/render.py` checks every controlled document and renders it to `docs/pdf/<doc_id>_v<version>.pdf`.
- `python .kit/drawing.py` (called from each project's `cad/src/sheets.py`) builds drawing sheets as SVG and PDF in `cad/drawings/`.
- The GitHub Action in `.github/workflows/docs.yml` runs the checks on every push and attaches PDFs to a GitHub Release whenever a release tag is pushed.
- Public releases follow section 14: `python .kit/release_gate.py` must pass, and the release tag is `v0.<TRL>.0` (for example `v0.3.0` at TRL 3).

## 9. Technology Readiness Level (TRL)

Each project states its maturity as a Technology Readiness Level on the NASA and US DOE 1 to 9 scale. The TRL rates this specific design, not the underlying technology. A sand battery is commercial elsewhere, but a new sand battery design starts at TRL 2 until evidence shows otherwise.

| TRL | Definition | Evidence the repo must contain |
| --- | --- | --- |
| 1 | Basic principles observed | Problem statement (PRB) |
| 2 | Technology concept formulated | Draft precis (PRC) and requirements (REQ) |
| 3 | Analytical or experimental proof of concept | Calculation note (CAL), working build123d model with STEP export, drawing sheet (DWG), priced BOM with every unit cost filled in, prototype build plan (BLD) with pictures, `design_state: constructable` |
| 4 | Components validated in the lab | Test report (TST) with `environment: lab`, build log entries |
| 5 | Validated in a relevant environment | Test report (TST) with `environment: relevant` |
| 6 | System prototype demonstrated in a relevant environment | Precis at version 1.0 or later with status Released, a drawing at a lettered revision (Rev A or later), and a system-level TST with `environment: relevant` |
| 7 to 9 | Operational demonstration through proven in service | Beyond portfolio scope; claim only with a named deployment partner and evidence |

Rules:

- `project.yaml` records `trl` (current level), `trl_target` (the level the current effort aims for) and `trl_evidence` (the files that support the claim).
- `python .kit/render.py --check` fails if the evidence for the claimed TRL is missing. CI runs this check on every push.
- Documentation alone cannot go past TRL 3. TRL 4 and above require hardware and a test report.
- TRL and visibility are independent. A repo can be public at TRL 3 as a documented design ready to build.
- A change of TRL is recorded in the build log with the date and the evidence that justified it.

## 10. Portfolio phase and TRL cap

`.kit/PHASE.yaml` sets the current phase. During the **populate** phase every repo is capped at **TRL 3**: `trl` and `trl_target` may not exceed 3, and the check fails if they do. Every repo targets the cap: `trl_target` must equal 3, so a new repo is taken all the way to TRL 3 (scaffold, populate and advance, see `/to-trl3`). Work that belongs to TRL 4 or later (building or testing hardware, test articles, test plans and reports, build-log entries, purchasing lists, PCB layouts) must not be started. The prototype build plan (BLD, section 18) is TRL 3 paper work and is required. Where it already exists it is kept, flagged in the check output, and not extended. Only Amish changes `PHASE.yaml`.

Every repo carries a `CLAUDE.md` with the working rules for AI sessions: the TRL cap, decision rights (nothing is recorded as decided unless Amish decided it), one step per session, and a mandatory `docs/REVIEW.md` before stopping.

## 11. Concept media

Every repo at TRL 2 or above explains its idea visually. Media are generated from a build123d massing model with `.kit/concept.py`, never drawn by hand, so they stay in step with the design.

| File | Required | Purpose |
| --- | --- | --- |
| `media/hero.png` | TRL 2+ | Shaded isometric render with a 1.75 m person for scale; the website card image |
| `media/concept-blueprint.png` and `.pdf` | TRL 2+ | Blueprint concept sheet: orthographic and isometric views, scale, key figures, title block |
| `media/model.glb` and `media/viewer.html` | TRL 2+ | Interactive 3D viewer (glTF plus model-viewer) for the website |
| `media/cutaway.png` | When the inside matters | Section view showing internal parts |
| `media/exploded.png` | Recommended | Exploded view with numbered callouts matching the BOM |
| `media/flow.png` | When energy or material moves | System, energy or material flow diagram with losses |

Session commands in `.claude/commands/` (`/populate`, `/advance-trl3`, `/rein-in`, `/refresh-media`) carry the standard prompts, so every Claude Code session starts from the same instructions.

At TRL 2 a massing model is enough: correct overall proportions and main components. All concept media carry "CONCEPT, NOT FOR FABRICATION". The check warns when required media are missing at TRL 2 and fails at TRL 3.

## 12. Product renders

Every repo at TRL 3 shows the product as it would look, not only as a massing model.

- `cad/src/product_model.py` is the appearance model. It defines `product_parts()` (named parts with a shape and a material), `TITLE` ("Name: what it is") and `RENDER_VIEWS`. It is for renders only: every main dimension comes from `cad/src/model.py`, never typed in again.
- Where the appearance model departs from `model.py` (a chamfer, a label, a fastener drawn for realism), record the deviation in `docs/REVIEW.md` as "Proposed, awaiting Amish".
- Scale comes from context, not from a floating figure: a hand or forearm for handheld objects, and the posed mannequin (`mannequin()` in `.kit/context_parts.py`: stand, walk, push, ride, sit, reach) for anything a person uses at body scale.
- Renders are made with `.kit/export_views.py` (one scene per view) and `.kit/photoreal.py` (Blender Cycles), then captioned with `.kit/photo_caption.py`. Files are `media/render-<view>.png`; `media/render-hero.png` is required.
- Every caption names the project, the repository and the viewing direction, and carries "CONCEPT, NOT FOR FABRICATION".
- Captions never sit on the render. `.kit/photo_caption.py` adds a header band (title, concept label, repository) above the render and a footer band (view note) below it, wraps every line to the image width, and steps the font down to a floor before adding a line.
- The README opens with `media/render-hero.png`.
- Software-only and scene repositories (no single product) may use a scene render as the hero instead of a product model.

## 13. Storefront images

Two images, both made from `media/render-hero.png` by `python .kit/cards.py .`:

| File | Size | Purpose |
| --- | --- | --- |
| `media/card.png` | 800 x 800 | Square thumbnail for the organization profile page |
| `media/social-preview.png` | 1280 x 640, under 1 MB | GitHub social preview, shown when a repository link is shared |

- The social preview shows the area, name, one-line description, the first sentence of the pitch, the brand line and the repository address. Design Molecule repos read "Design Molecule · open hardware concept, TRL n"; OpenRatio repos read "OpenRatio · research and educational prototype, TRL n".
- GitHub has no API for the social preview. Upload it under the repository's Settings, Social preview, on release day.
- Regenerate both images whenever `render-hero.png` changes.

### Image quality

Every render, card and social preview must be clear and readable. `python .kit/image_qc.py` checks each one, and the release gate blocks on any failure:

| Check | Rule |
| --- | --- |
| Layout | Made by the current `photo_caption.py` or `cards.py`, which store the text layout in the PNG |
| Text inside the image | Every line at least 1.2 % of the image width from each edge; nothing runs off the side |
| No overlap | No line of text touches another line, and no caption text sits on the render |
| Text size | Render captions at least 1.05 % of the image width in pixel height (17 px at 1600 px); social preview text at least 16 px |
| Resolution | Renders at least 1200 px wide; card 800 x 800; social preview 1280 x 640 and under 1 MB |
| Sharpness | The render is not blurred or upscaled (edge sharpness at least 15 on the `image_qc.py` scale) |

Long titles and notes wrap to more lines rather than shrinking below the floor. The social preview shortens the pitch sentence with an ellipsis only if it cannot fit at the smallest size.

## 14. Public release

A repository goes public only when Amish approves it, and only after `python .kit/release_gate.py` passes. The gate checks:

1. `render.py --check` passes (document control, TRL cap, concept media).
2. Storefront: hero render, card, social preview under 1 MB, README leading with the hero, and every image passing the image quality check (section 13).
3. Issue templates in `.github/ISSUE_TEMPLATE/`: question, build report, design suggestion. The build report template restates that the design is a TRL 3 concept, not released for fabrication (OpenRatio: a research and educational prototype, not a medical device).
4. `CITATION.cff` valid, with an author ORCID.
5. License files match `project.yaml`.
6. No em dashes in the repository's own text.
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

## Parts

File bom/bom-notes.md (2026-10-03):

# BOM notes

Prices are TRL 3 estimates (2026-09-25) from supplier types, not quotes from named suppliers. Line numbers match the callouts in `media/exploded.png` and Table 1 of EGD-PRC-001. Quantities and lengths follow `cad/src/model.py`.

- Kit parts total $707.00 (18 lines). Value-engineering target: USD 605. Estimated cost of the constructable design: USD 707 (USD 102 over the target). R13 is over the target by 17 %; savings worth trying are in the Value engineering section of EGD-DEC-001. The total is computed by `docs/04-calcs/sizing.py` (EGD-CAL-001 v0.6, G1).
- Changes for construction (EGD-DDR-003, 2026-10-01): line 1 adds slip-on flanges, aluminium wall plates, crossover plates and U-bolts ($48 to $80); line 2 adds the verge cleat, bent arm, pod plate and lens hood to each pod ($28 to $37 each); line 9 adds a pole-mount tilt bracket ($32 to $38); line 13 has longer pod cables and a valve cable ($30 to $33); line 16 adds the valve board, pipe clips, saddle and fascia clips, four M20 glands and the battery strap ($25 to $50). Lines 7 and 14 are respecified at the same price.
- Changes from the first TRL 3 BOM ($571): the ridge-line sensor head (item 2, $45) is replaced by two gutter-corner sensor pods ($56, EGD-DDR-002, O3); item 13 adds two pod cables ($20 to $30); the battery (item 8) goes from 6 Ah to 10 Ah ($32 to $45, O5).
- The TRL 2 indicative total was about $420. Most lines were underpriced at TRL 2 (thermal sensors, enclosures, siren and switch); item 17, a mast earthing kit, was added for the lightning safety note.
- The "Option" row (metal eave runs, $110) is priced but not in the kit total. Under D4 metal eave runs were chosen if the budget allowed; it does not.
- Decided on 2026-10-02 (EGD-DEC-001) and now in `bom.csv`: line 7 is mounted on the shadiest available wall in its light finish; line 9's charge controller has a battery temperature probe and stops charging above 45 °C ($38 to $42: panel $18, tilt bracket $6, controller $18 against about $14 for a plain one); new line 18 is the folded white sun shade over the enclosure ($14: sheet $5, flat bar $3, white paint $2, screws, plugs and rivets $4). Spray lines stay black as bought (they are drawn blue only in the concept media).
- Not included: the water source (tank), the pump and its power supply (out of scope, D6), the supply hose, gutter guards (listed in the installation notes where deep debris collects, decided 2026-10-02), tools and installation labour. A SwapCell pack for pump option (c) would be priced once in SwapCell and excluded from this kit.

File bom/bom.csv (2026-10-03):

item | qty | spec | supplier | unit_cost_usd | make_buy | notes
1 Mast standoffs and crossover plates | 1 | 40 x 2 mm 6061-T6 aluminium tube, 2.45 m, with an end cap and cable grommet; two DN25 (33.7 mm) galvanized steel pipe standoffs about 740 mm; two slip-on base flanges for 33.7 mm tube; two 140 x 140 x 8 mm aluminium wall plates (made); two 100 x 100 x 6 mm aluminium crossover plates (made); eight M8 U-bolts (four for 40 mm tube, four for 33.7 mm pipe) with nyloc nuts; eight M10 wall anchors | Metal stockist (tube) and hardware shop (pipe and fixings) | 80.00 | buy | TRL 3 estimate (tube $18, pipe $12, flanges $16, plate stock $14, U-bolts $12, anchors $8); dimensions from cad/src/model.py; bonded to item 17; changed for construction (EGD-DDR-003)
2 Sensor pods with hoods and brackets | 2 | Die-cast aluminium box about 100 x 80 x 70 mm with 4 mm walls; 150 x 130 mm hood bent from 1 mm stainless on four 15 mm M4 spacers; lens hood bent from 1 mm stainless; pod node board (small microcontroller and RS-485 transceiver) on standoffs; M16 cable gland; mount made from aluminium: verge cleat (80 x 80 x 6 mm angle, 140 mm), arm (40 x 6 mm flat bar, about 530 mm, bent twice) and pod plate (120 x 70 x 6 mm); two M6 bolts with spacers, M8 pivot bolt, two 8 mm coach screws | Enclosure distributor; local sheet-metal shop; electronics distributor; hardware shop | 37.00 | buy | TRL 3 estimate per pod (box $10, hood and lens hood $6, node $8, mount $11, gland and fixings $2); mount changed for construction (EGD-DDR-003) | hood $5 | node $8 | bracket $5); replaces the ridge-line sensor head (EGD-DDR-002 O3)
3 Thermal array sensor | 2 | MLX90640 BAB (55 x 35 degree lens), 32 x 24 pixels, I2C, on a breakout board | Electronics marketplace or distributor | 48.00 | buy | TRL 3 estimate per sensor | one in each pod; branded breakouts cost about $60 to $75
4 Anemometer and wind vane | 1 | Weather-station spare cup anemometer (reed-switch pulse output) and wind vane (resistor ladder) with 460 mm crossarm | Weather-station spares supplier | 38.00 | buy | TRL 3 estimate
5 Temperature and humidity sensor | 1 | SHT4x-class probe in a five-plate radiation shield with mast clamp | Electronics distributor; weather-station spares supplier | 20.00 | buy | TRL 3 estimate
6 Controller board | 1 | ESP32-class module with Wi-Fi on a protoboard carrier: two logic-level MOSFET valve drivers with PWM holding-current reduction, siren driver, RS-485 transceiver, 12 V to 3.3 V buck, input fuse and terminals | Electronics distributor | 28.00 | buy | TRL 3 estimate; firmware beyond a labelled sketch and any PCB layout are TRL 4 work
7 Ground enclosure | 1 | Steel IP65 wall box about 160 x 320 x 400 mm with a gear plate on studs and four wall lugs, light-colored powder coat | Electrical wholesaler | 40.00 | buy | TRL 3 estimate; mounted on the shadiest available wall in its light finish (decided 2026-10-02); the sun shade is line 18 (EGD-CAL-001 section F)
8 Battery | 1 | 12.8 V 10 Ah LiFePO4 with built-in BMS and low-temperature charge cut-off, about 128 Wh | Battery supplier | 45.00 | buy | TRL 3 estimate; fused output; raised from 6 Ah (EGD-DDR-002 O5)
9 Solar panel and charge controller | 1 | 10 W 12 V panel; pole-mount tilt bracket (mast clamp, arm and rail); PWM charge controller with LiFePO4 profile and a battery temperature probe that stops charging above 45 C (decided 2026-10-02) | Solar supplier | 42.00 | buy | TRL 3 estimate (panel $18, tilt bracket $6, controller with temperature probe $18; a plain LiFePO4 PWM controller is about $14); tilt bracket added for construction (EGD-DDR-003); temperature cut-off decided 2026-10-02
10 Zone valve | 2 | 12 V DC normally closed solenoid valve, DN20 (3/4 in), direct-acting or zero-minimum-pressure type, about 6 W coil | Irrigation supplier | 15.00 | buy | TRL 3 estimate per valve; manifold fittings in item 16
11 Pressure transducer | 1 | 0 to 10 bar (0 to 150 psi), 0.5 to 4.5 V output, 1/4 in NPT | Electronics marketplace | 13.00 | buy | TRL 3 estimate
12 Pump-start relay | 1 | Isolated relay module, dry contact, 10 A | Electronics distributor | 6.00 | buy | TRL 3 estimate; signals the pump's own certified controls only
13 Mast and pod cables | 1 | 10 m shielded 4-pair outdoor cable for the mast, run inside the mast tube; two shielded 4-pair pod cables of 6 m (front) and 10 m (back) along the arms, under the verge and down the gable wall; 2 m twin cable to the valves; 1 m silicone heat sleeve at each pod | Electrical wholesaler | 33.00 | buy | TRL 3 estimate; lengths from cad/src/model.py
14 Eave spray lines and heads | 1 | 50 m roll of 16 mm UV-stable polyethylene line (model needs 39 m: two 12.5 m eave runs and two risers up the gable wall corner and under the gutter), 12 micro-sprinklers about 40 L/h at 2 bar on tees, 24 gutter-lip clips, elbows, end plugs and tees | Irrigation supplier | 52.00 | buy | TRL 3 estimate; polyethylene eave runs are the baseline (EGD-DDR-001 D4); metal eave runs are the priced option below
15 Siren status light and key switch | 1 | 12 V piezo siren about 100 dB, LED beacon, keyed arm and disarm switch | Electronics distributor | 20.00 | buy | TRL 3 estimate
16 Hardware fittings and valve board | 1 | Valve board (3 mm aluminium, 1,100 x 270 mm, made); manifold pipe with three tees and a hose connector; two stand-off pipe clips; saddle clips for the risers and cables; two stand-off clips under the fascia; four M20 cable glands; battery strap (1.5 mm aluminium, made); wall plugs and screws, cable ties, fuse holders and fuses | Hardware shop | 50.00 | buy | TRL 3 estimate; valve board, clips, glands and strap added for construction (EGD-DDR-003); no exploded-view callout
17 Mast earthing kit | 1 | 1.2 m copper-clad earth rod, clamp, 6 m of 16 mm2 green-yellow conductor, mast bonding clamp | Electrical wholesaler | 26.00 | buy | TRL 3 estimate; added at TRL 3 for the lightning safety note; follow local practice
18 Enclosure sun shade | 1 | Folded white sun shade over the ground enclosure: 1 mm aluminium sheet blank about 650 x 470 mm, cut, folded into a top plate 360 x 440 mm with a 100 mm front flap and two 100 mm side flaps, and painted white; two arms of 40 x 6 mm flat bar about 400 mm, each bent with a 40 mm wall tab; two M6 wall screws with plugs; four 4 mm rivets | Local sheet-metal shop and hardware shop | 14.00 | buy | TRL 3 estimate (sheet $5, flat bar $3, white paint $2, screws, plugs and rivets $4); made by the builder from stock; dimensions from cad/src/model.py; decided 2026-10-02 (EGD-DEC-001)
Option: metal eave runs | 1 | Replace the two 13.2 m polyethylene eave runs with 1/2 in copper or galvanized steel tube and fittings | Plumbing supplier | 110.00 | buy | Priced option; not in the kit total (EGD-DDR-001 D4)

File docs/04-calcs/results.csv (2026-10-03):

id | requirement | value_trl3 | target | status
R6 | Wet the gutter and roof edge | Leeward-only rule: leeward eave 1.5 mm/h at 8.3 m/s, 5.1 mm/h at 4.2 m/s; windward eave wetted only after a windward detection (screening model) | 5 mm/h net at 30 km/h | Not met
R13 | Stay within the budget | $707 | $605 kit parts | Not met
R1 | Detect a smouldering ignition | Gutter debris in view 1.25 to 12.95 m from the gutter end; 100 x 50 mm hot face reaches 2 K to 41 m; flat 100 cm2 spot reaches it to 12.1 m (1.6 K at 13 m); hanger straps hide debris 42 mm below the lip at 83 of 118 stations | 100 cm2 at 300 C, 1.5 to 13 m along the gutters, 10 s | At risk
R2 | Detect single landed embers | 600 C ember reaches the 2 K trigger to 8.8 m centred in a pixel, 4.4 m on a pixel corner; false-trigger rate at 2 K unknown | 10 mm, 600 C, within 8 m, 10 s | At risk
R10 | Survive fire weather | Mast 14 MPa (factor 16.6); standoff factor 4.7; pod arm factor 19; enclosure 63 C in sun at 60 C ambient with the shade (charging stops above 45 C); pods exposed at the gutters | 120 km/h; -10 to 60 C | At risk
R11 | Install without roof work or mains | Mast on wall plates, pod arms on verge cleats, lip clips, 12 V only; install time not estimated | No penetrations; 12 V; 6 h, two people | Not verifiable at TRL 3
R3 | Watch both roof planes | Gutter interiors in view 1.25 to 12.95 m from the east end, both gutters (open gutter; see R1 for hanger straps) | Both gutters, 1.5 m to far end | Met
R4 | Arm only in fire weather | Arming logic as specified; defaults adjustable | 30 km/h or 50 km/h gusts, RH 20 % or less, 10 min | Met
R5 | Start water quickly | 54 s worst zone, detection-side zone first | 60 s | Met
R7 | Use little water | 4 L/min; 965 L per 4 h event | 4 L/min; 1,000 L | Met
R8 | Work through a grid outage | 67 Wh needed; 115 Wh usable at 25 C, 104 Wh at 0 C, 92 Wh at end of life | 72 h armed plus 4 h spraying on the kit battery | Met
R9 | Fail safely | Normally closed valves; fail-to-wet on sensor loss; alarms | As specified | Met
R12 | Tell people what it is doing | Siren, beacon, log; phone alerts need a network | As specified | Met

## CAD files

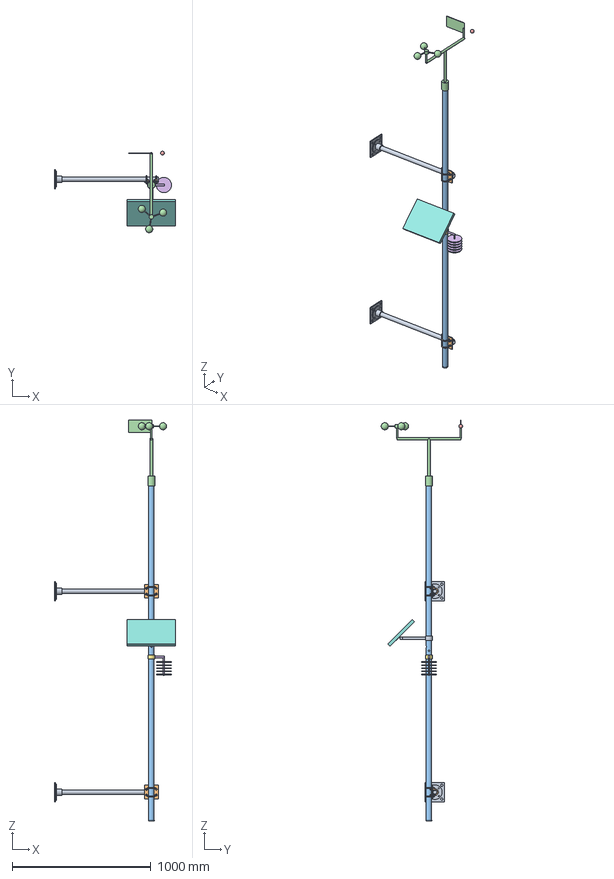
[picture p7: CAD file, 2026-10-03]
cad/step/mast-assembly.step
875.0 x 588.5 x 2893.0 mm

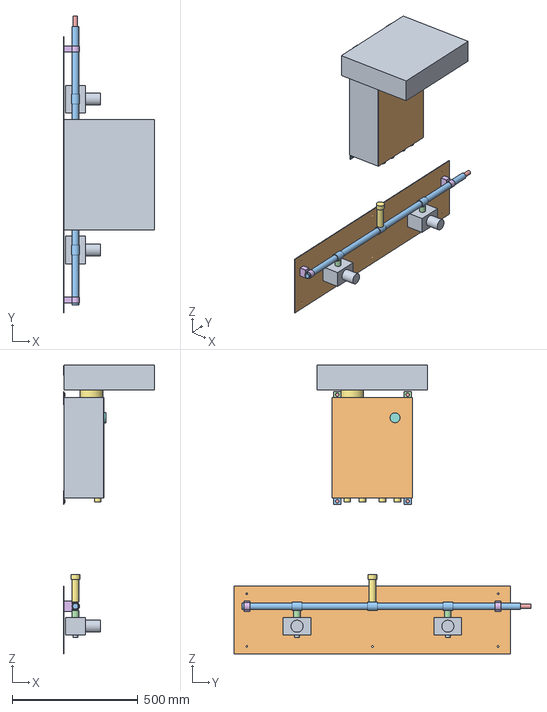
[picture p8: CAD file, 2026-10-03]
cad/step/ground-unit.step
363.0 x 1180.0 x 1150.0 mm

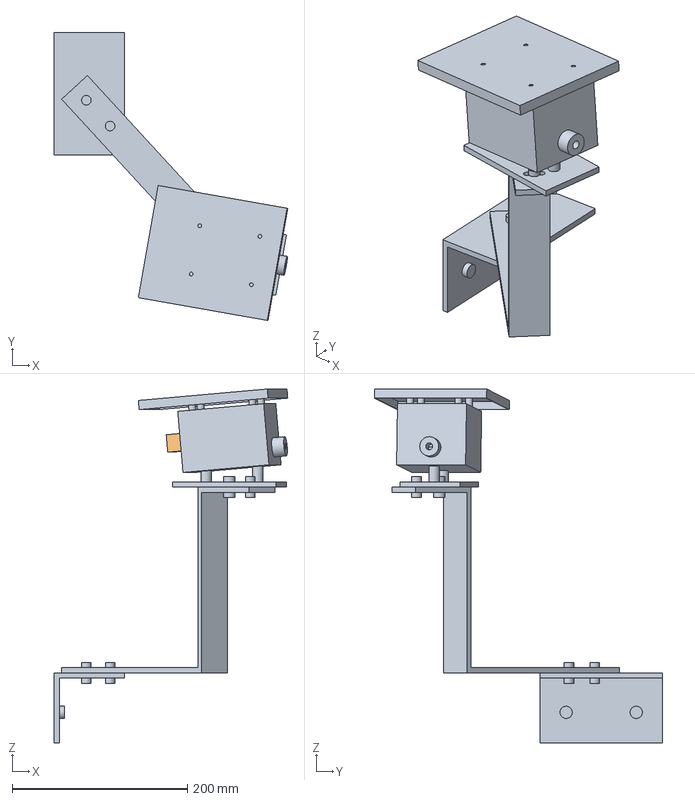
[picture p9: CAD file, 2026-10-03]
cad/step/sensor-pod.step
266.7 x 328.8 x 404.0 mm

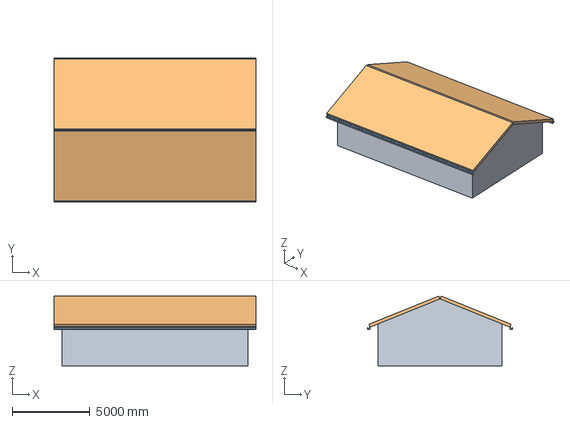
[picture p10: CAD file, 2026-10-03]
cad/step/reference-house.step
13000.0 x 9290.0 x 4501.5 mm

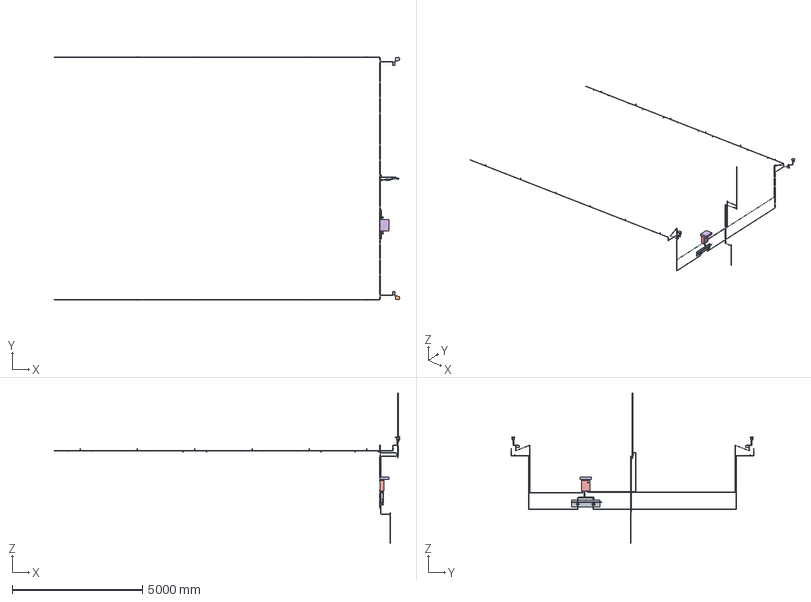
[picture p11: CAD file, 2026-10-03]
cad/step/emberguard-kit.step
13278.5 x 9348.0 x 5760.0 mm

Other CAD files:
cad/stl/emberguard-kit.stl
cad/stl/ground-unit.stl
cad/stl/mast-assembly.stl
cad/stl/reference-house.stl
cad/stl/sensor-pod.stl

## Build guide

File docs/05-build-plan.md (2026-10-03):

---
doc_id: EGD-BLD-001
title: EmberGuard prototype build plan
project: EmberGuard
doc_type: Build plan
version: "0.4"
status: Draft
date: '2026-10-02'
author: Amish Chadha
license: CERN-OHL-S-2.0
revisions:
  - version: "0.1"
    date: '2026-10-01'
    author: Amish Chadha
    change: First build plan; design made constructable (EGD-DDR-003)
  - version: "0.2"
    date: '2026-10-01'
    author: Amish Chadha
    change: Budget treated as a value-engineering target
  - version: "0.3"
    date: '2026-10-02'
    author: Amish Chadha
    change: EGD-DDR-003 accepted by Amish on 2026-10-02
  - version: "0.4"
    date: '2026-10-02'
    author: Amish Chadha
    change: Sun shade over the enclosure (making sketch EGD-DWG-114, step 18), charge controller with a 45 °C cut-off, gutter guard note, pictures redrawn; kit cost $707
---

# EmberGuard prototype build plan

**Plan, not yet built.** How to build the first proof-of-concept prototype, component by component. Building and testing to it is TRL 4 work. Decisions still to be made are kept in the design decisions register ([docs/06-design-decisions.md](06-design-decisions.md)), not here.

## 1. What you are building

Figure 1. Every component, pulled apart and numbered in build order

*Figure 1. Every component pulled apart and numbered in build order, in three groups each drawn at its own scale. One of the two sensor pods is shown.*

The prototype is one EmberGuard kit fitted to the east gable end of a single-storey house like the 12 x 8 m reference house: a 2.45 m aluminium mast held 700 mm off the gable wall by two steel standoffs, carrying the wind sensors, a humidity sensor and a 10 W solar panel; two small sensor pods, each on an arm screwed to the end of the roof overhang beyond a gutter, looking along that gutter with a thermal camera; a steel ground enclosure on the gable wall, under a folded white sun shade, holding the battery, controller and relay; a valve board below it with two zone valves; and a spray line clipped along each gutter lip with six micro-sprinklers. Figure 1 shows the 27 components in the order you make or fit them. Fourteen are made or drilled in a small workshop: the wall plates, standoff pipes, crossover plates, mast tube, pod boxes, lens hoods, pod hoods, pod plates, pod arms, verge cleats, enclosure, battery strap, valve board and sun shade. Everything else is bought and fitted: the sensors, panel, battery, electronic modules, valves, flanges, U-bolts, line, heads and clips. The work is sawing, drilling, tapping, bending flat bar, folding thin stainless sheet, wiring bought modules with screw terminals, and fixing to a house wall from a ladder. The parts cost about $707 from the bill of materials, against a value-engineering target of $605.

> **Safety:** Fitting the kit means working at height at the roof edge. Use a stable ladder with a second person footing it, never stand on the roof covering, and do not work in wind, rain or on a wet or mossy surface. The kit holds a 12.8 V lithium iron phosphate battery of about 128 Wh: keep its fuse out until section 6 says otherwise. It runs on 12 V DC only; the pump keeps its own mains supply and certified controls, and EmberGuard touches it only through a dry contact. The mast is the highest point on the house and must be earthed before it is left standing. EmberGuard never replaces evacuation: nobody stays behind to watch or operate it during a fire.

## 2. What changed to make it buildable

The concept showed what EmberGuard does; many of its parts could not be made or fixed as drawn. Each change below keeps what the kit does, and all of them except the last are recorded in decision record EGD-DDR-003, accepted by Amish on 2026-10-02; the last is in the design decisions register.

*Table 1. Changes from the concept.*

| Component | The concept had | The buildable design has | Why |
| --- | --- | --- | --- |
| Mast standoffs | Pipes running into the middle of the mast through solid collars; pipes butted onto 12 mm wall plates | Pipes passing beside the mast, joined by a crossover plate and four U-bolts; slip-on flanges bolted to aluminium wall plates (Figures 3 and 6) | No welding and no holes in the mast or pipe |
| Mast cable | Up the outside of the mast, through the standoff collars and the humidity sensor's arm | Inside the mast tube, out through the end cap, under the lower standoff (Figure 8) | Protected from embers; nothing in its way |
| Solar panel | Floating 42 mm off its arm, facing away from the sun | Facing the equator at 45 degrees on a clamp, arm and tilt rail (Figure 9) | A real fixing, facing the right way |
| Weather sensors | Shield plates and the wind sensor head floating on the mast | Shield on a centre rod and mast clamp; wind sensors on a sleeve over the mast top | How the bought spares fit |
| Pod mount | A clamp block buried in the gutter end and a thin rod post | A cleat screwed to the end of the roof overhang, a bent flat bar arm and a pod plate that sets the aim (Figures 15 and 18) | A gutter cannot carry a pod 500 mm above it; the verge board can |
| Thermal sensor | Looking down a 70 mm tube through a wall with no hole; the tube would have cut its view to less than half | Sensor in a small window in the pod wall with a short lens hood that clears the full 55 x 35 degree view (Figure 11) | Keeps the view the gutter coverage depends on |
| Pod hood | A slab floating above the pod | Folded stainless sheet on four spacers, with an air gap (Figure 13) | A fixing, and shade for the box |
| Ground enclosure | Floating off the wall; cables in through the top; battery and boards floating inside | Wall lugs; glands in the bottom; battery strapped on the floor; boards on the gear plate (Figures 20 and 21) | Fixed, sealed and entered from below |
| Valves | Floating 250 mm off the wall, in line on the manifold so one would block the other | On their own tees under a manifold on a wall-mounted valve board (Figure 25) | Each zone runs on its own |
| Spray lines | Risers standing free and passing up through the gutter; the eave line floating above the lip | Risers on wall clips up the gable corner, out under the gutter and up in front of it; eave line in lip clips (Figures 26 and 27) | Supported all the way; nothing through the gutter |
| Cables and earthing | Pod cables in the air beyond the house; no earthing in the model | Cables along the arms, under the verge and down the wall; earth clamp, conductor and rod (Figure 8) | Every run supported and shown |
| Enclosure heat | A mid-grey box in full sun; a plain charge controller | A light-coloured box on the shadiest available wall under a folded white sun shade (Figure 28); a charge controller that stops charging above 45 °C | Keeps the battery within its charging limit in fire weather |

## 3. Making the components

Make and check each component before the assembly step that needs it. Sizes are in millimetres. "East" is away from the gable wall, "front" is the eave nearer the street (zone A), "back" the other eave (zone B). Workshop tolerance is 0.5 mm unless a step says otherwise; drawings do not carry tolerances before TRL 4.

### 3.1 Wall plates (make 2)

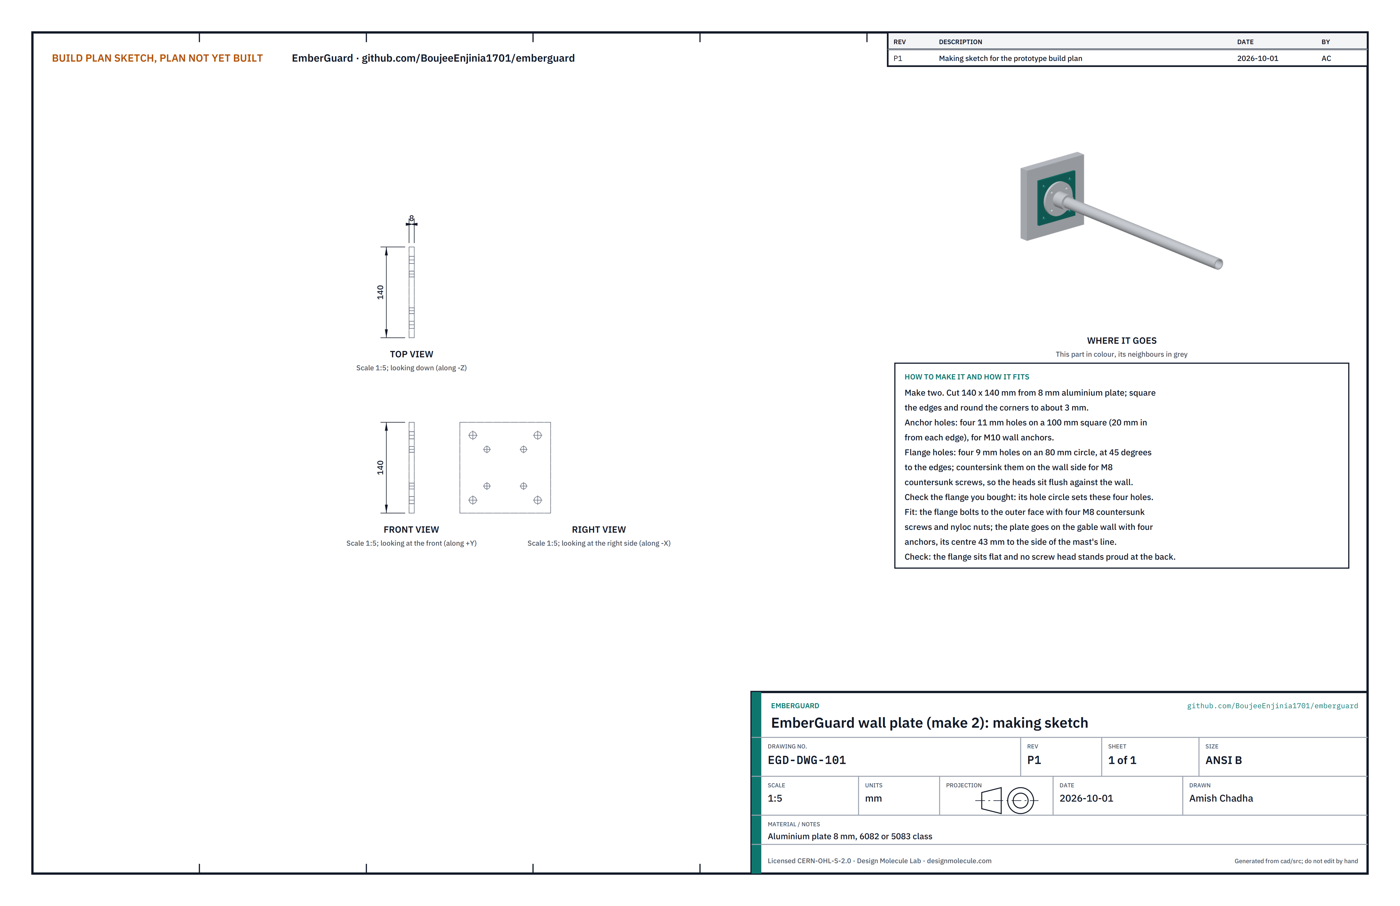
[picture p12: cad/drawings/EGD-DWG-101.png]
Figure 2. Making sketch of the wall plate


*Figure 2. Wall plate making sketch (EGD-DWG-101).*

**What it is and what it is made from.** The square plate that carries each standoff on the gable wall. Aluminium plate 8 mm thick, 6082 or 5083 class, 140 x 140 mm.

**How to make it.**

1. Cut two blanks 140 x 140 mm. File the edges square and round the corners to about 3 mm.
2. Mark the centre. Anchor holes: four 11 mm holes on a 100 mm square, 20 mm in from each edge.
3. Flange holes: four 9 mm holes on an 80 mm circle, on the diagonals. Check this circle against the flange you bought first.
4. Countersink the four flange holes on the wall side so the M8 countersunk screw heads sit flush.
5. Deburr both faces.

**How it fits the parts next to it.**

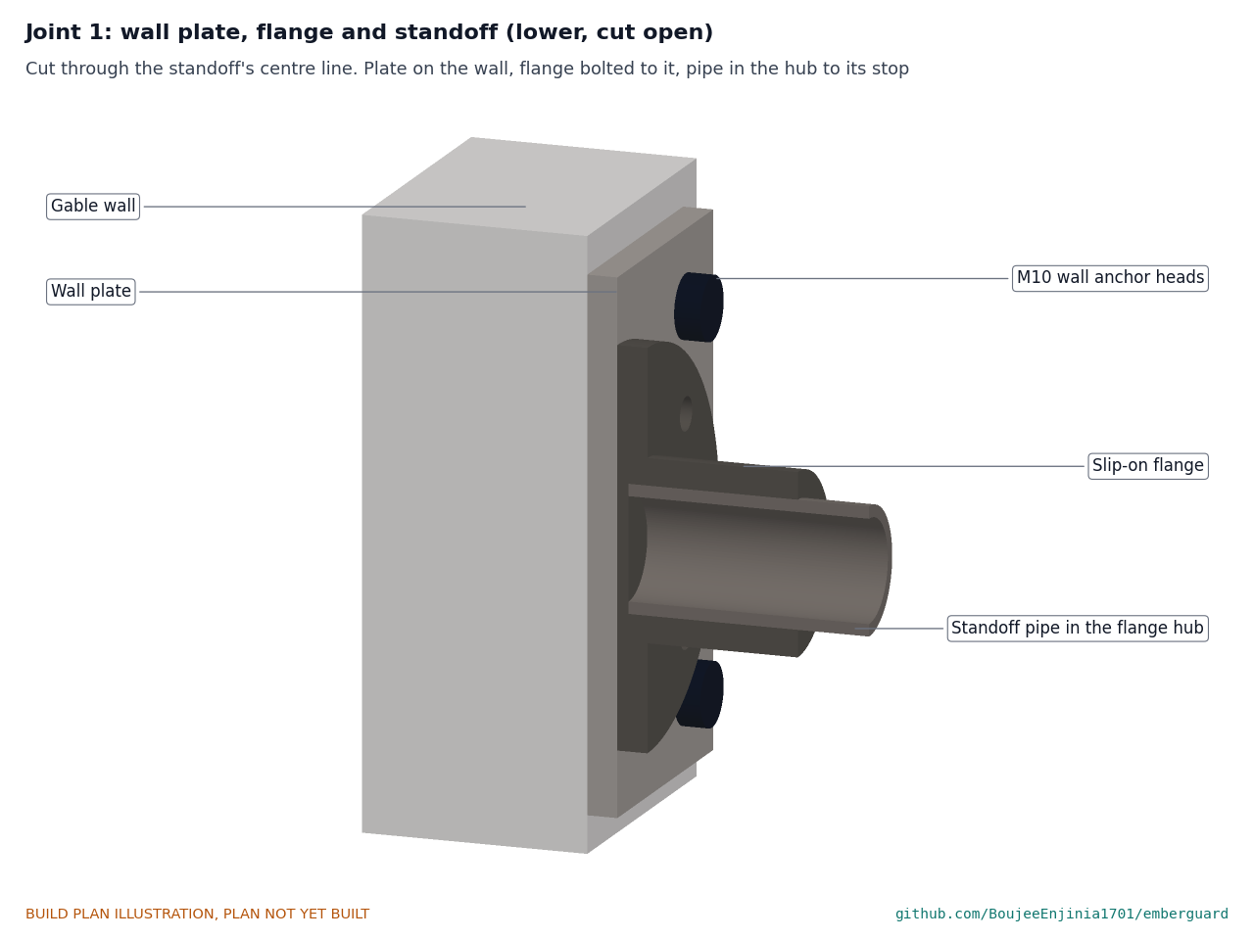
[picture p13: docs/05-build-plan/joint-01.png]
Figure 3. Joint 1: wall plate, flange and standoff


*Figure 3. The plate lies flat on the wall; the flange is bolted to its outer face; the standoff pipe goes into the flange hub to its stop.*

The plate's back lies flat on the gable wall, held by four M10 anchors, its centre 43 mm to the side of the mast's line (toward the back eave) and 2.45 m or 3.90 m above the ground. The flange sits flat on its outer face on four M8 countersunk screws with nyloc nuts on the flange side.

**Check before moving on.** With the flange bolted on, the plate's back is flat: no screw head stands proud.

### 3.2 Standoff pipes (make 2)

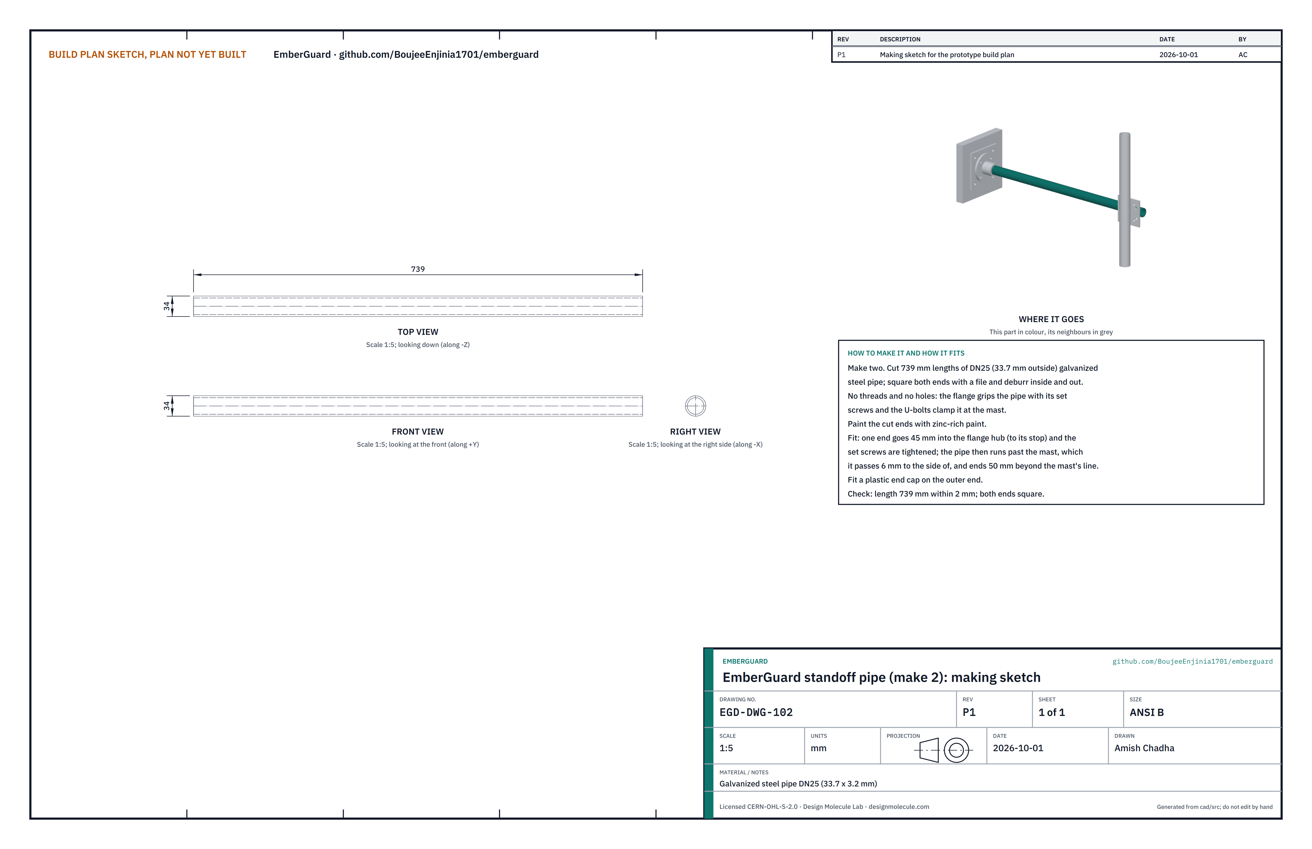
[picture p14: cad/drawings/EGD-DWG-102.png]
Figure 4. Making sketch of the standoff pipe


*Figure 4. Standoff pipe making sketch (EGD-DWG-102).*

**What it is and what it is made from.** The arm that holds the mast 700 mm out from the wall. Galvanized steel pipe DN25, 33.7 mm outside, 3.2 mm wall.

**How to make it.**

1. Cut two 739 mm lengths with a pipe cutter or hacksaw. Square the ends with a file and deburr inside and out.
2. Paint the cut ends with zinc-rich paint and let it dry.
3. Push a plastic end cap onto one end of each.

**How it fits the parts next to it.** The plain end goes 45 mm into the flange hub, to its stop, and the flange's set screws grip it. The pipe runs straight out from the wall, passes 6 mm beside the mast and ends 50 mm beyond it; the crossover plate lies between the two (Figure 6).

**Check before moving on.** Length 739 mm within 2 mm; both ends square.

### 3.3 Crossover plates (make 2)

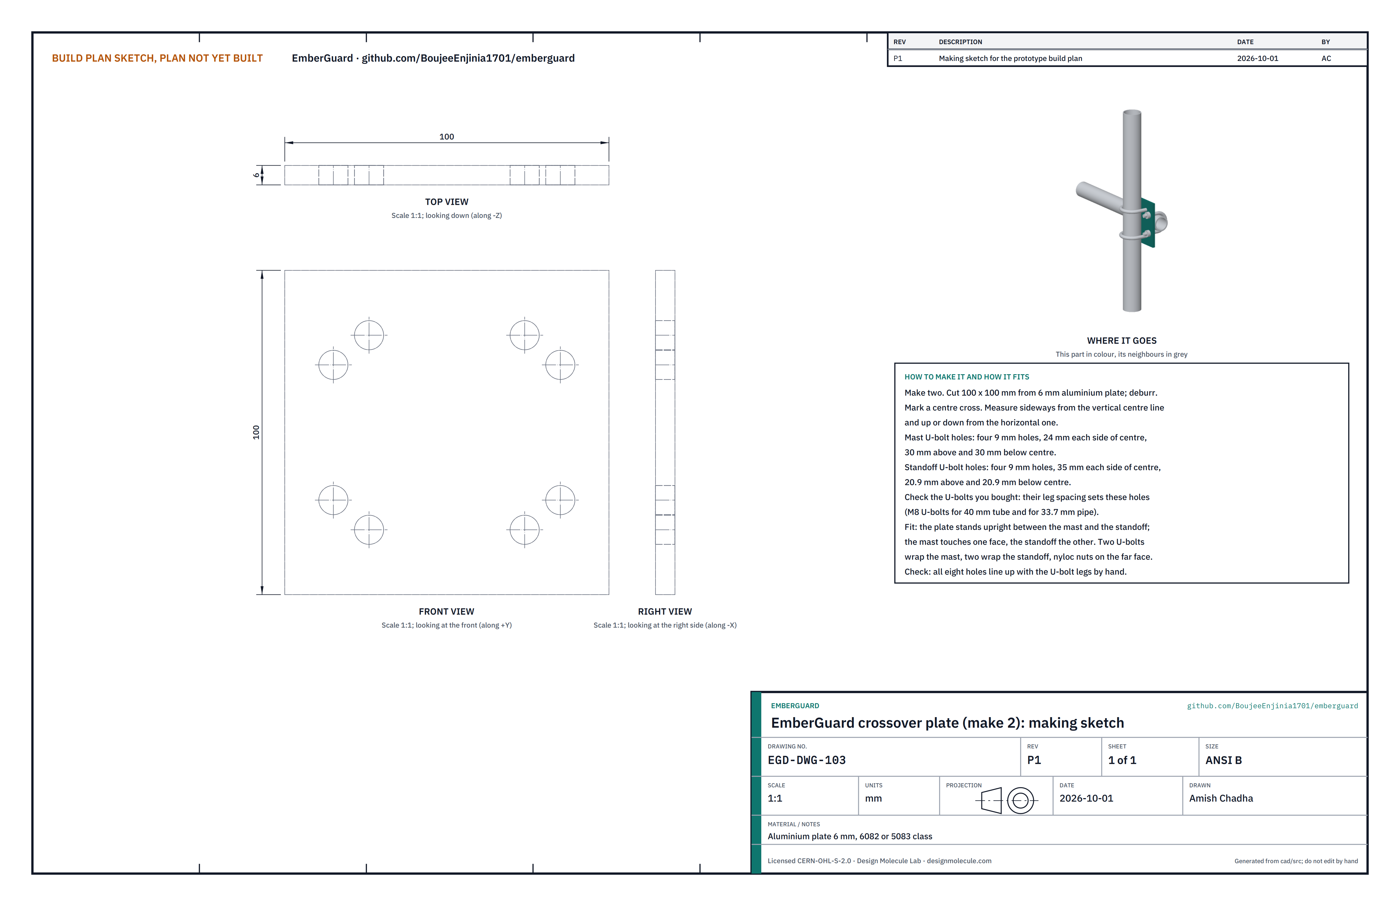
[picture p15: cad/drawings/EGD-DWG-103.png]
Figure 5. Making sketch of the crossover plate


*Figure 5. Crossover plate making sketch (EGD-DWG-103).*

**What it is and what it is made from.** The plate that joins the mast to each standoff at right angles. Aluminium plate 6 mm, 6082 or 5083 class, 100 x 100 mm.

**How to make it.**

1. Cut two 100 x 100 mm blanks; deburr.
2. Mark a centre cross. Mast U-bolt holes: four 9 mm holes, 24 mm each side of the vertical centre line, 30 mm above and below the horizontal one.
3. Standoff U-bolt holes: four 9 mm holes, 35 mm each side of the vertical centre line, 20.9 mm above and below the horizontal one. Check both patterns against the U-bolts you bought first.
4. Drill the two plates clamped together so they match.

**How it fits the parts next to it.**

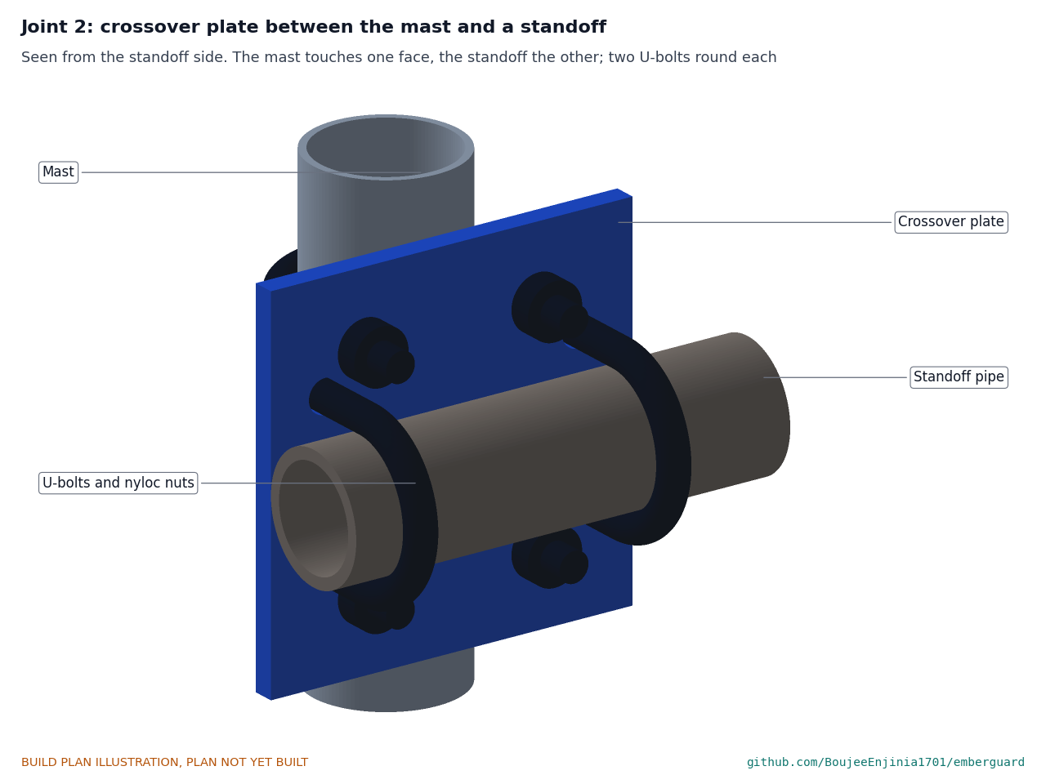
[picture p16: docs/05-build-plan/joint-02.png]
Figure 6. Joint 2: crossover plate


*Figure 6. The mast touches one face, the standoff the other; two M8 U-bolts wrap each, with nyloc nuts on the opposite face.*

The plate stands upright, its faces parallel to the standoff. The mast lies against the face toward the front eave, the standoff against the face toward the back eave. The mast's U-bolts go round the mast and through the plate to nuts on the standoff side, above and below the pipe; the standoff's U-bolts go round the pipe and through to nuts on the mast side, either side of the mast.

**Check before moving on.** All eight U-bolt legs drop through their holes by hand.

### 3.4 Mast tube and what it carries

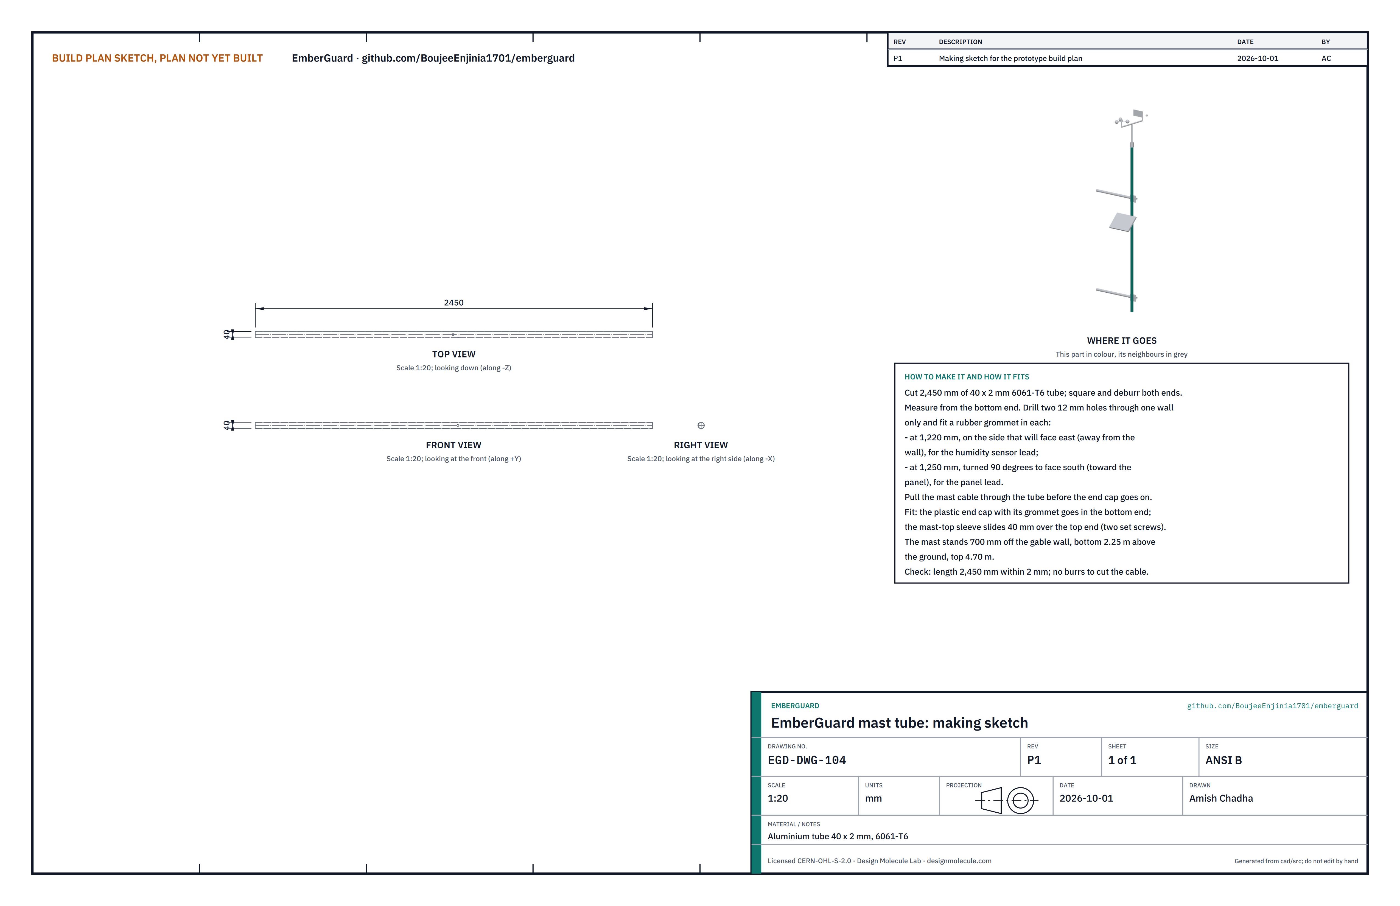
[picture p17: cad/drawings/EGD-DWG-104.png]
Figure 7. Making sketch of the mast tube


*Figure 7. Mast tube making sketch (EGD-DWG-104).*

**What it is and what it is made from.** The upright that carries the wind sensors at its top, the humidity shield and the solar panel. Aluminium tube 40 x 2 mm, 6061-T6, 2,450 mm long.

**How to make it.**

1. Cut 2,450 mm of tube; square and deburr both ends, inside as well, so nothing can cut the cable.
2. Measuring from the bottom end, drill one 12 mm hole through one wall at 1,220 mm on the side that will face east, and one at 1,250 mm on the side that will face south. Fit a rubber grommet in each.
3. Pull the mast cable through the tube from the top, leaving 1 m out at the top for the wind sensors and enough at the bottom to reach the enclosure. Feed the humidity and panel leads in through their grommets.
4. Push the plastic end cap, with the cable through its grommet, into the bottom end.

**How it fits the parts next to it.**

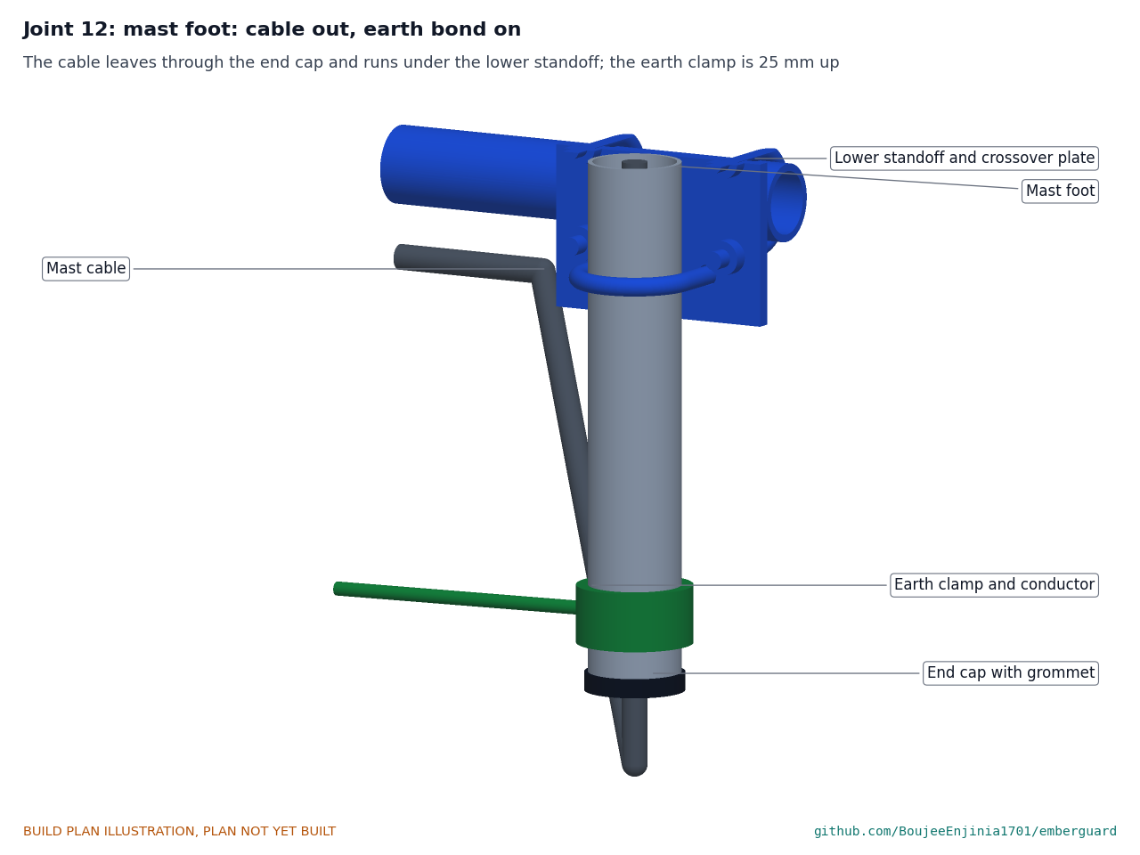
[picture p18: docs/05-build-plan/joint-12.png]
Figure 8. Joint 12: mast foot


*Figure 8. The cable leaves through the end cap and runs under the lower standoff to the wall; the earth clamp sits 25 mm up from the foot.*

The mast stands upright 700 mm off the gable wall, on the ridge line, its foot 2.25 m above the ground and its top 4.70 m. The two crossover plates hold it at 2.45 m and 3.90 m. The wind sensors' sleeve slides 40 mm over the top and is locked by two set screws. The humidity shield's clamp goes round the tube with its arm just above the shield, the clamp's centre 1,175 mm up the tube; the panel clamp's centre is 1,310 mm up.

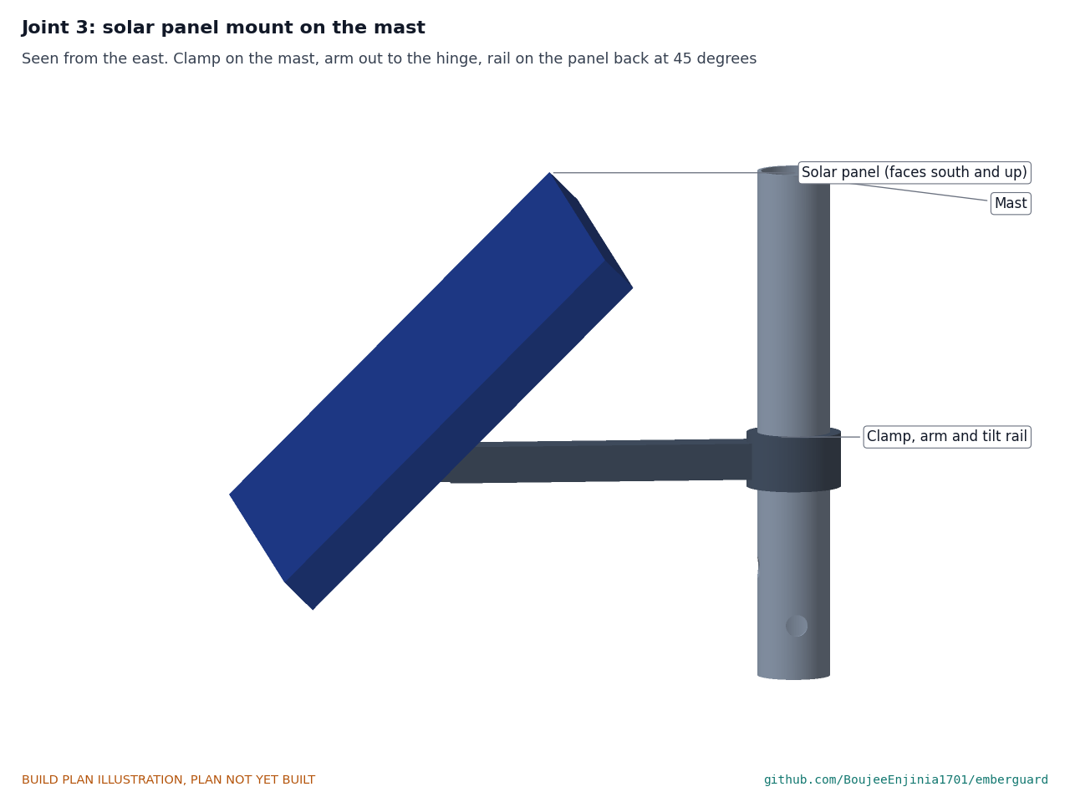
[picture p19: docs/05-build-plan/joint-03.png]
Figure 9. Joint 3: solar panel mount


*Figure 9. The panel clamp on the mast, the arm out to the hinge and the tilt rail bolted to the panel's frame at 45 degrees.*

**Check before moving on.** The cable slides freely in the tube; the grommets are seated; the end cap is tight.

### 3.5 Pod boxes, drilled (make 2)

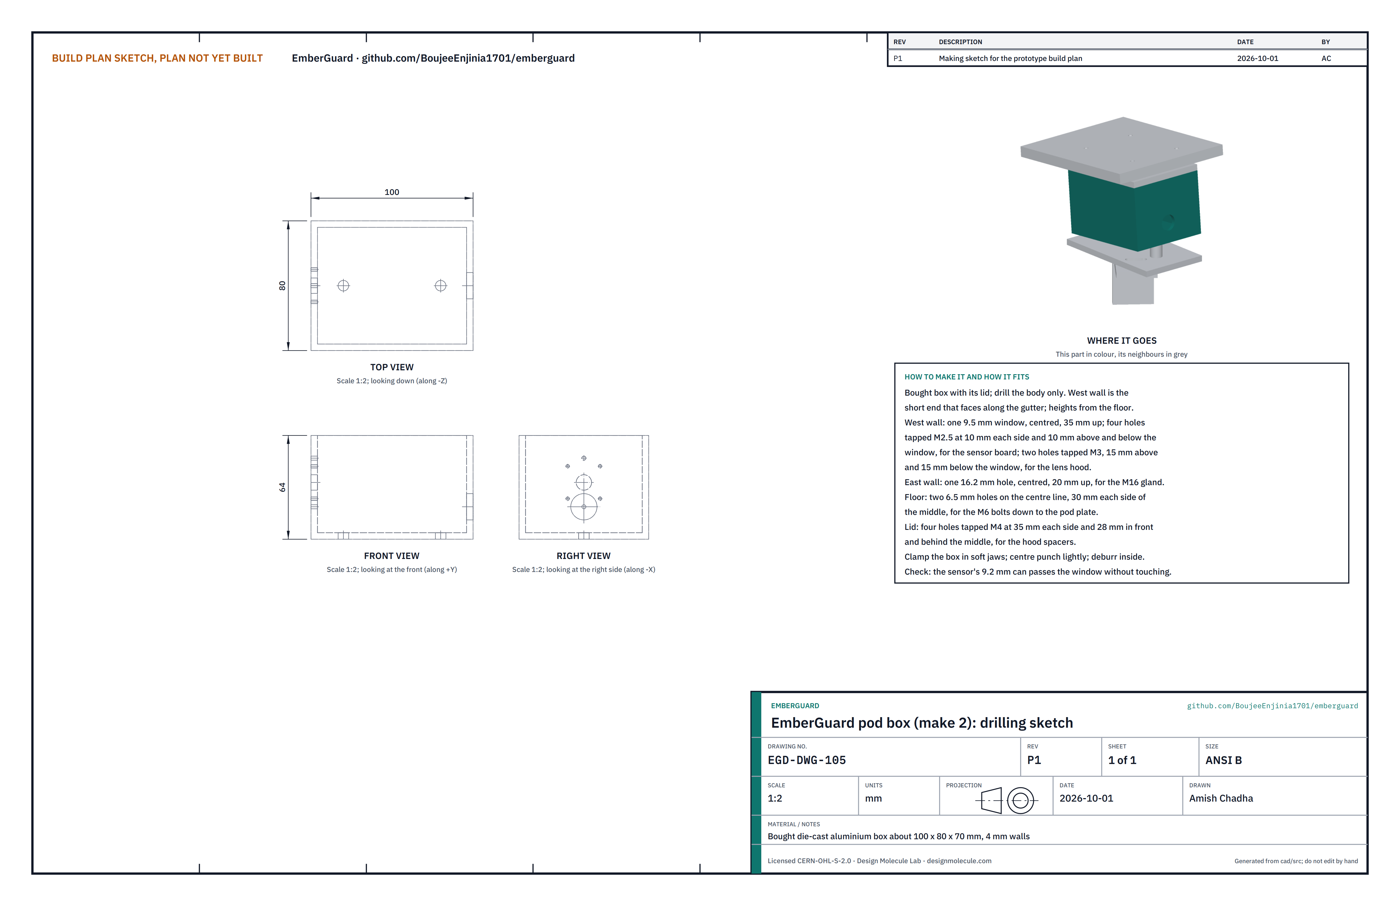
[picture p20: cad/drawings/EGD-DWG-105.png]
Figure 10. Drilling sketch of the pod box


*Figure 10. Pod box drilling sketch (EGD-DWG-105).*

**What it is and what it is made from.** A bought die-cast aluminium box about 100 x 80 x 70 mm with 4 mm walls and a screwed lid, holding the thermal sensor and the pod node board. Five kinds of hole are drilled in it.

**How to make it.**

1. Hold the box in soft vice jaws. The west wall is one of the two short ends; it will face along the gutter.
2. West wall: one 9.5 mm window in the middle, 35 mm up from the box's underside. Around it, four holes drilled 2.05 mm and tapped M2.5, 10 mm each side and 10 mm above and below the window. Above and below the window, 15 mm from it, two holes drilled 2.5 mm and tapped M3.
3. East wall: one 16.2 mm hole in the middle, 20 mm up, for the M16 cable gland.
4. Floor: two 6.5 mm holes on the long centre line, 30 mm each side of the middle.
5. Lid: four holes drilled 3.3 mm and tapped M4, 35 mm each side of the middle along the box and 28 mm across it.
6. Deburr every hole inside and out and blow out the chips.

**How it fits the parts next to it.**

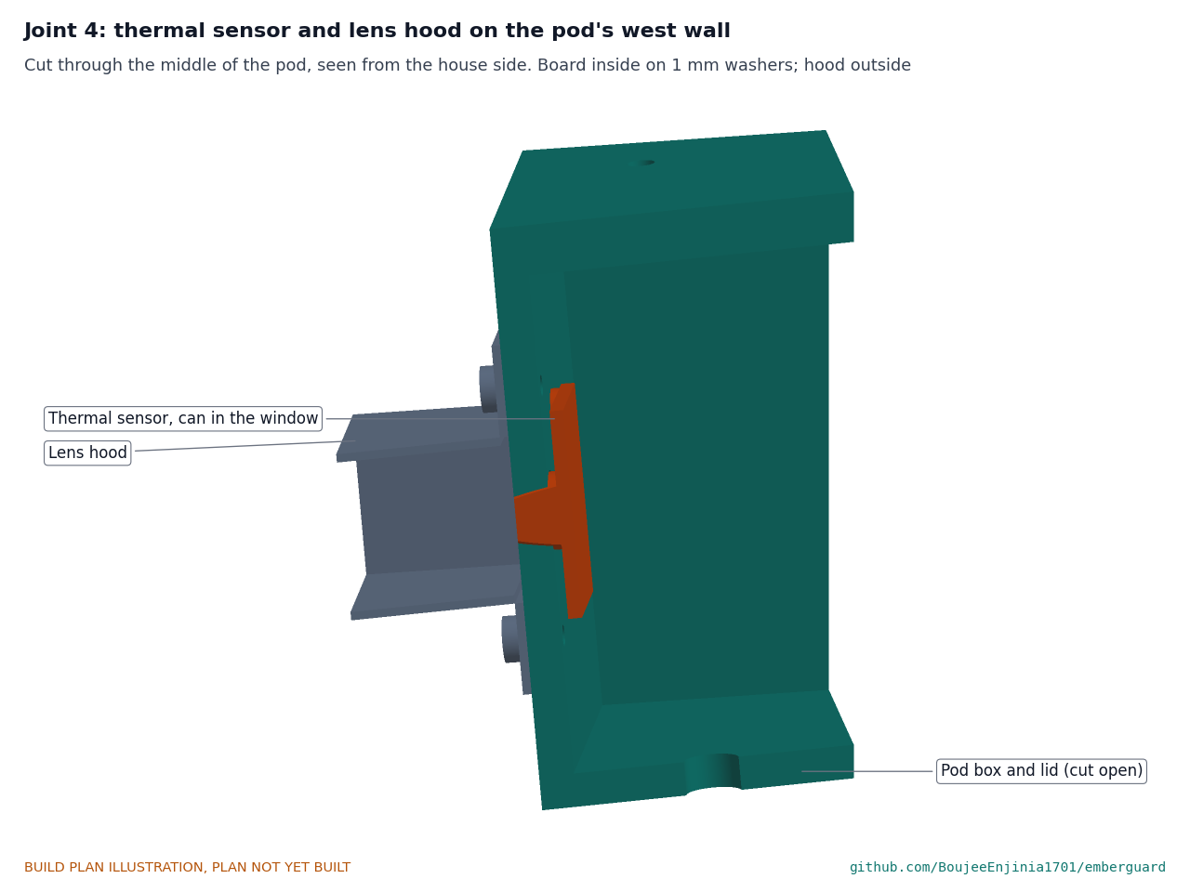
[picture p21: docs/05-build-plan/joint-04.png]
Figure 11. Joint 4: thermal sensor and lens hood


*Figure 11. The sensor board sits on the inside of the west wall on four M2.5 screws over 1 mm washers, its can in the window and sealed by an O-ring; the lens hood is on the outside.*

The thermal sensor's 9.2 mm can sits in the window with its face flush with the outside of the wall; a 9.5 mm O-ring round the can, squeezed between the board and the wall, seals it. The node board stands on four 12 mm standoffs on the floor toward the east end, clear of the two bolt heads inside the floor. The pod cable comes in through the M16 gland in the east wall.

**Check before moving on.** The can passes the window without touching it; the board sits flat on its washers.

### 3.6 Lens hoods (make 2)

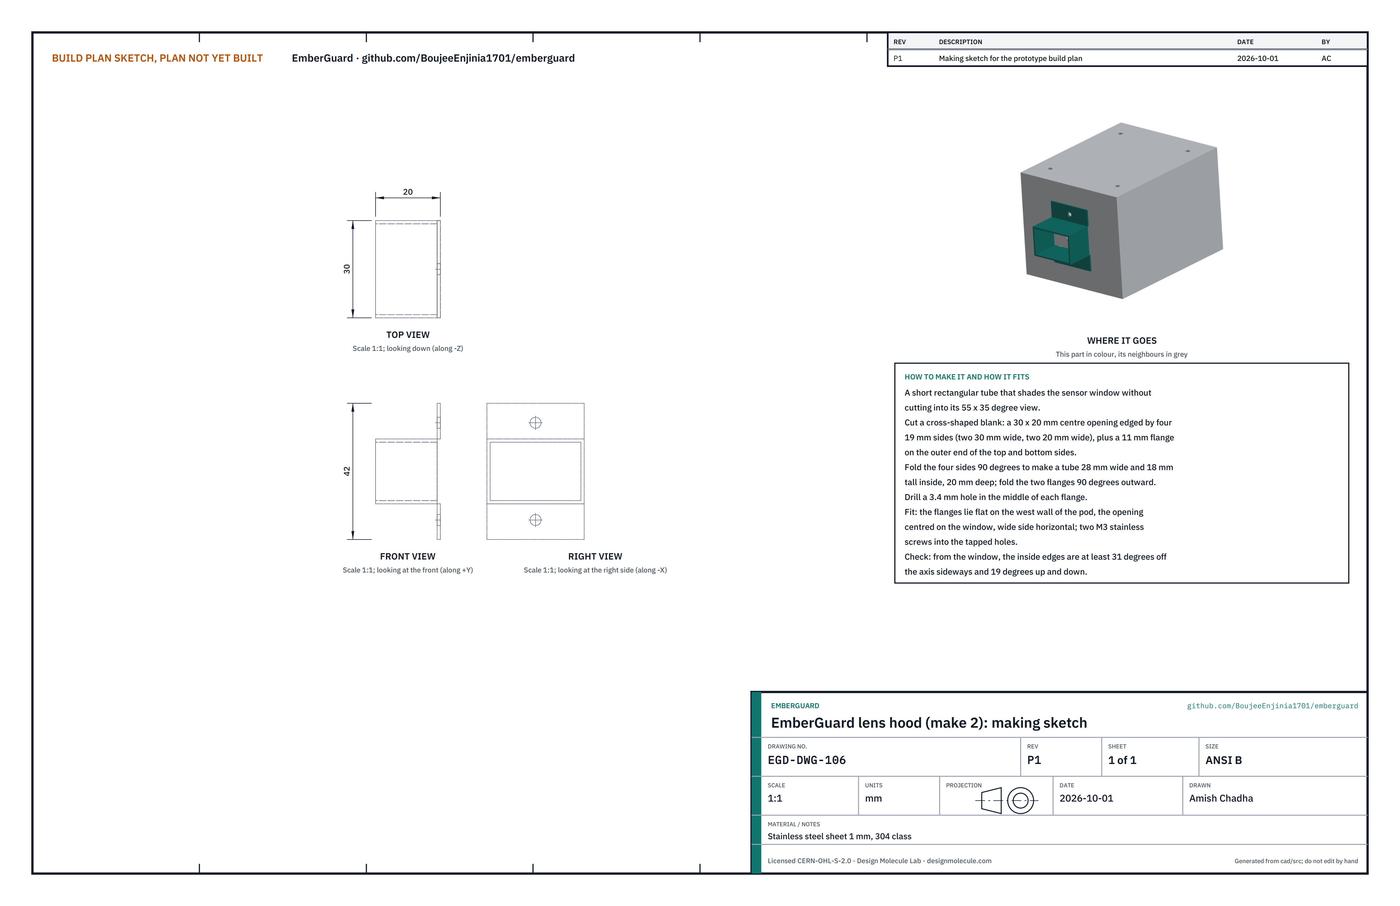
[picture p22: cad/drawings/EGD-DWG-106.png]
Figure 12. Making sketch of the lens hood


*Figure 12. Lens hood making sketch (EGD-DWG-106).*

**What it is and what it is made from.** A short rectangular tube that shades the sensor window from above and the sides without entering its view. Stainless steel sheet 1 mm, 304 class.

**How to make it.**

1. Cut a cross-shaped blank: a 30 x 20 mm centre opening edged by four 19 mm sides, two 30 mm wide and two 20 mm wide, with an 11 mm flange on the outer end of each wide side.
2. Fold the four sides through 90 degrees to make a tube 28 mm wide and 18 mm tall inside, 20 mm deep. Fold the two flanges 90 degrees outward.
3. Drill a 3.4 mm hole in the middle of each flange.

**How it fits the parts next to it.** The flanges lie flat on the west wall, the opening centred on the window with its long side level, held by two M3 stainless screws (Figure 11). From the window, the inside edges are 31 degrees off the axis sideways and 19 degrees up and down, outside the sensor's 27.5 and 17.5 degrees.

**Check before moving on.** Looking in through the hood from 1 m away along the axis, you can see the whole window with no edge of the hood across it.

### 3.7 Pod hoods (make 2)

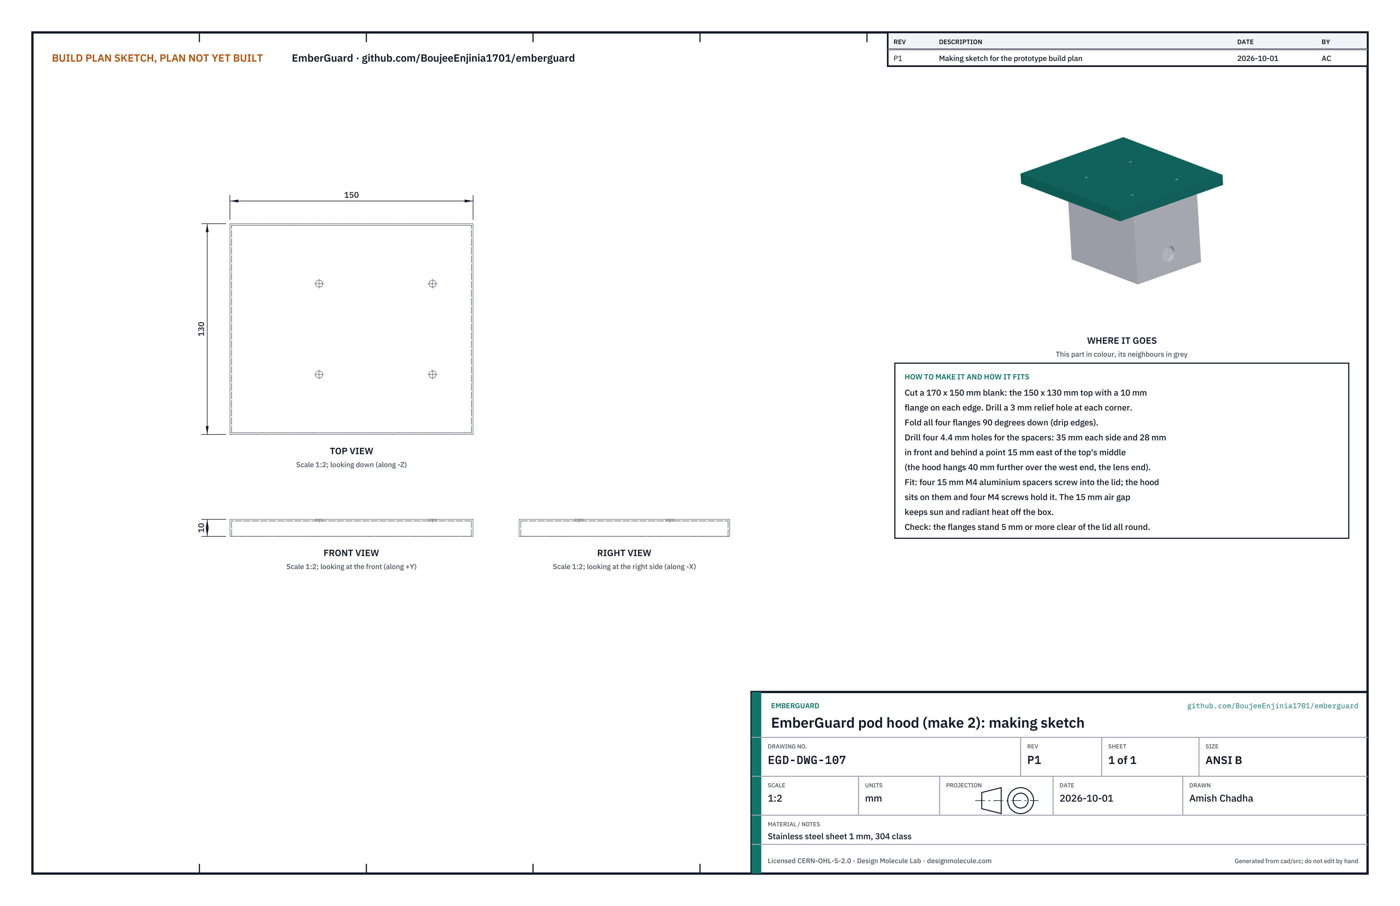
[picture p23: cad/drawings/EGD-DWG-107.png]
Figure 13. Making sketch of the pod hood


*Figure 13. Pod hood making sketch (EGD-DWG-107).*

**What it is and what it is made from.** The roof over the pod that keeps sun and radiant heat off it. Stainless steel sheet 1 mm, 304 class.

**How to make it.**

1. Cut a 170 x 150 mm blank: a 150 x 130 mm top with a 10 mm flange on every edge. Drill a 3 mm relief hole at each corner where the fold lines cross.
2. Fold all four flanges 90 degrees down.
3. Drill four 4.4 mm holes, 35 mm each side and 28 mm in front of and behind a point 15 mm east of the middle of the top, so the hood hangs 40 mm further over the lens end.

**How it fits the parts next to it.** Four 15 mm M4 aluminium spacers screw into the lid's tapped holes; the hood sits on them and four M4 screws hold it. The air gap is 15 mm, and the drip flanges stand 5 mm clear of the lid.

**Check before moving on.** The hood sits level on all four spacers.

### 3.8 Pod plates (make 2: a front and a back)

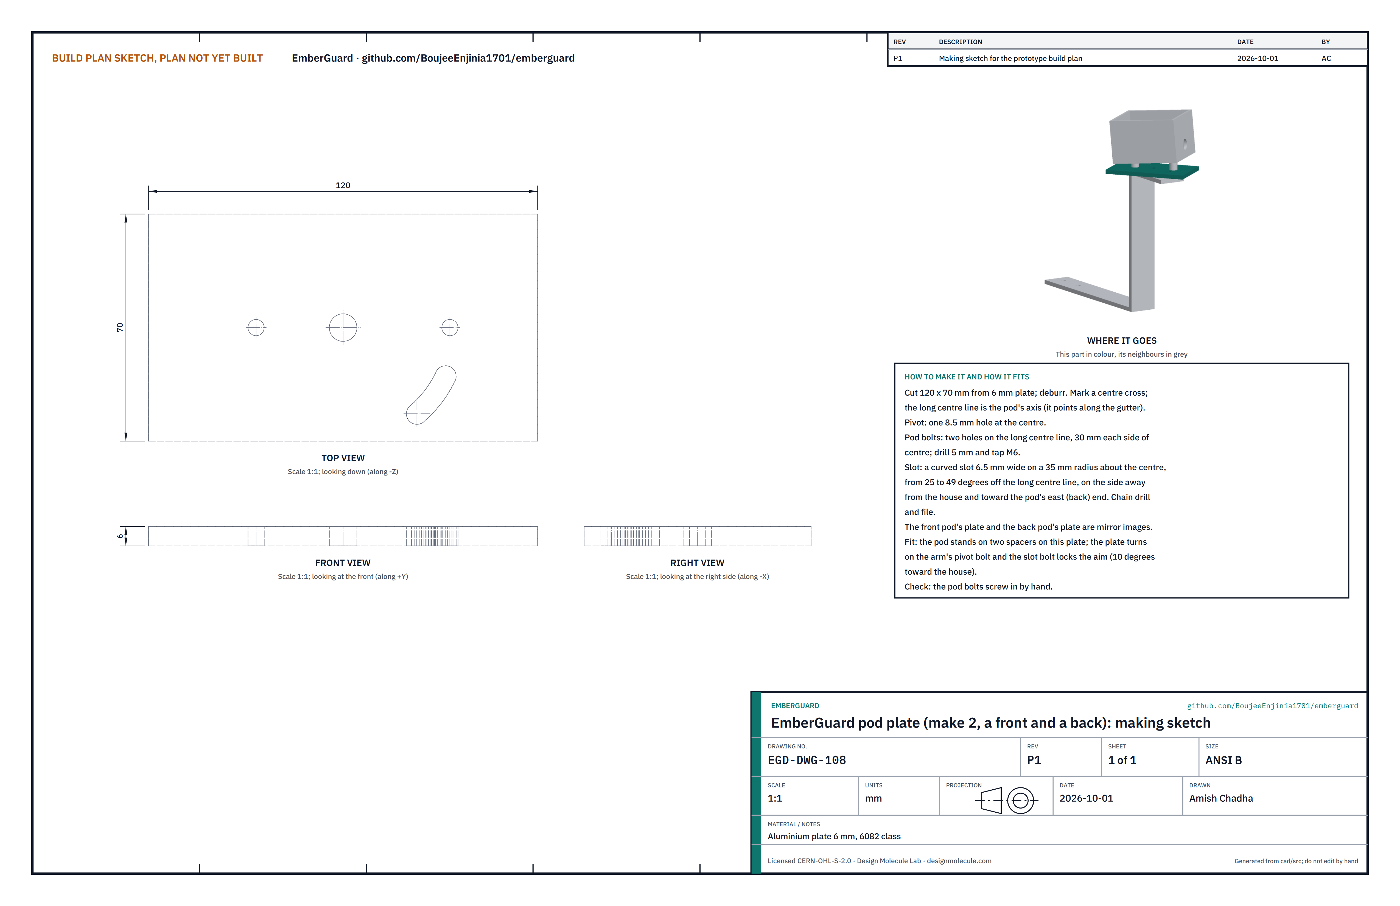
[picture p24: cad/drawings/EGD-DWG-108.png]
Figure 14. Making sketch of the pod plate


*Figure 14. Pod plate making sketch (EGD-DWG-108).*

**What it is and what it is made from.** The plate the pod stands on; it turns on the arm to aim the pod. Aluminium plate 6 mm, 6082 class, 120 x 70 mm.

**How to make it.**

1. Cut two 120 x 70 mm blanks; deburr. Mark the long centre line: it is the pod's axis.
2. One 8.5 mm pivot hole at the centre.
3. Two holes on the long centre line, 30 mm each side of the centre, drilled 5 mm and tapped M6.
4. A curved slot 6.5 mm wide on a 35 mm radius about the centre, from 25 to 49 degrees off the long centre line, on the side away from the house and toward the pod's east end. Chain drill along the arc and file smooth. The front and back plates are mirror images.

**How it fits the parts next to it.**

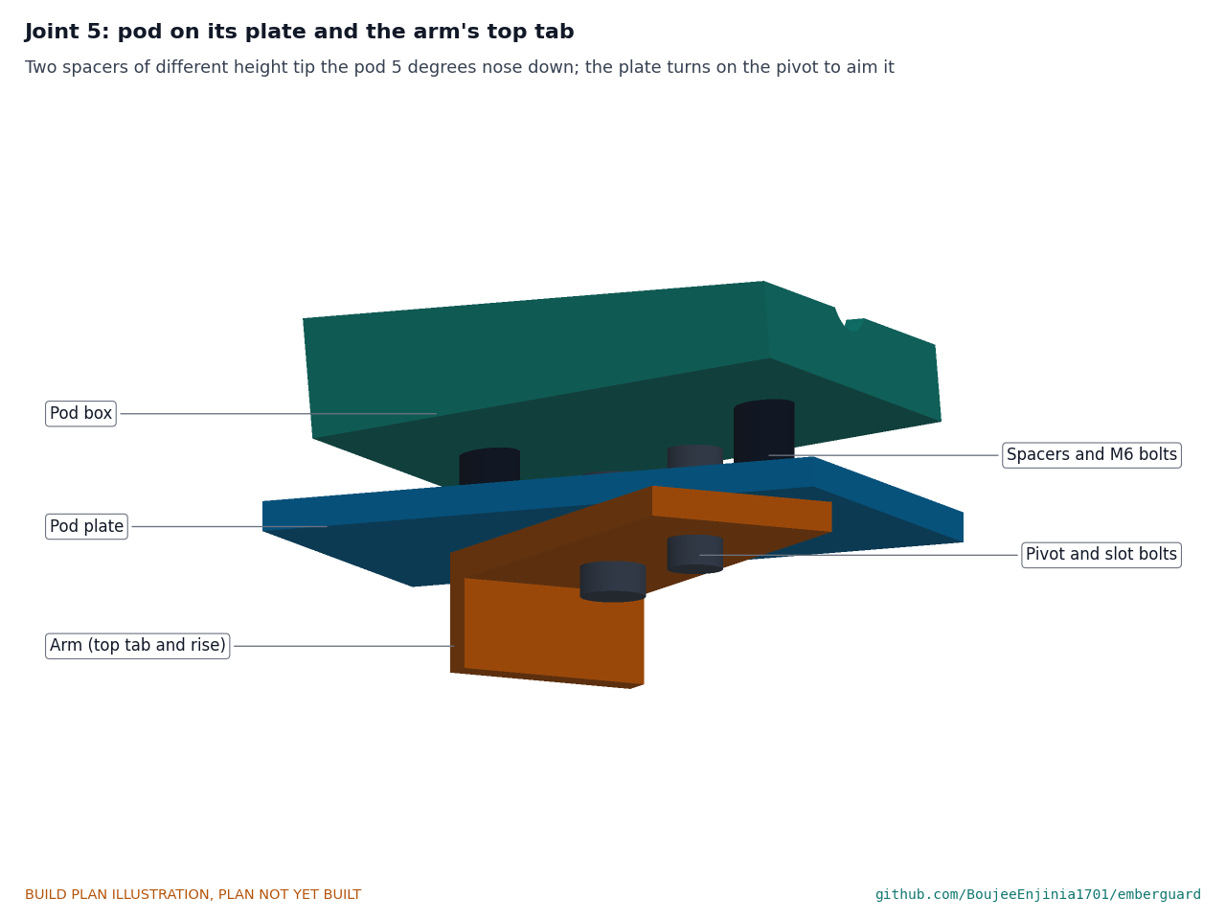
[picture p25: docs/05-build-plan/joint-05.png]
Figure 15. Joint 5: pod on its plate and the arm's tab


*Figure 15. The pod stands on two spacers of different height, which tip it 5 degrees nose down; the plate turns on the pivot bolt and the slot bolt locks the aim.*

The pod stands on two aluminium spacers, about 12.5 mm under the lens end and 17.7 mm under the other end, with a domed washer on each. Two M6 bolts go down from inside the pod, through the spacers, into the tapped holes. The plate lies flat on the arm's top tab, on an M8 pivot bolt with a nyloc nut, and an M6 bolt through the slot and the tab locks it.

**Check before moving on.** With the pod bolted on, an angle finder on the pod's lid reads 5 degrees nose down, give or take 1 degree.

### 3.9 Pod arms (make 2)

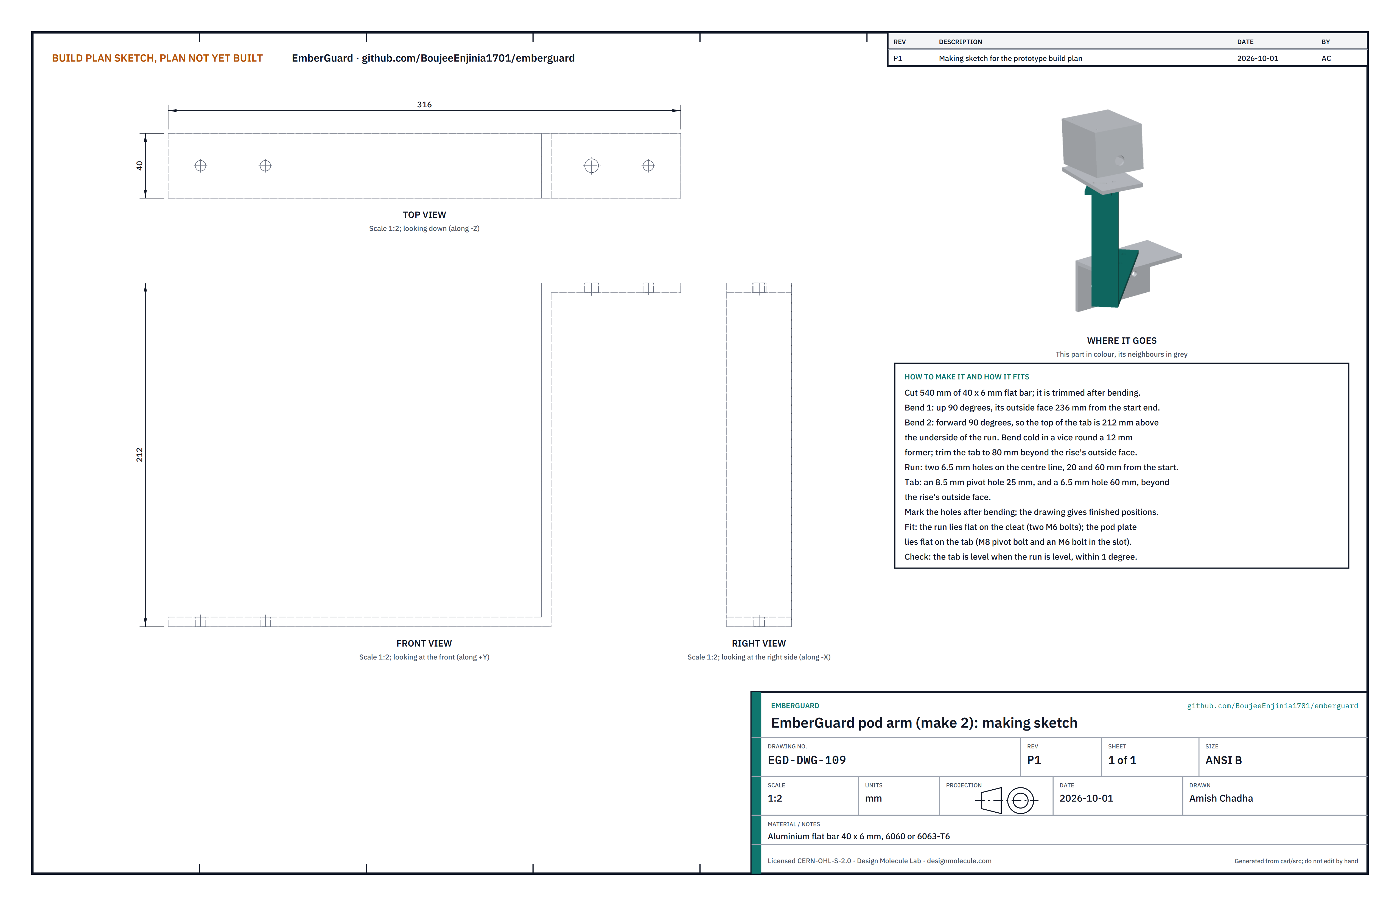
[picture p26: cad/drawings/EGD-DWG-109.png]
Figure 16. Making sketch of the pod arm


*Figure 16. Pod arm making sketch (EGD-DWG-109), drawn laid square.*

**What it is and what it is made from.** The bracket that carries a pod out from the verge cleat and up to its height. Aluminium flat bar 40 x 6 mm, 6060 or 6063-T6.

**How to make it.**

1. Cut 540 mm of bar for each arm.
2. Bend 1: up through 90 degrees, its outside face 236 mm from the start end. Bend cold in a vice round a 12 mm former.
3. Bend 2: forward through 90 degrees, so that the top of the tab is 212 mm above the underside of the run.
4. Trim the tab to 80 mm beyond the rise's outside face.
5. On the run, two 6.5 mm holes on the centre line, 20 and 60 mm from the start end. On the tab, an 8.5 mm pivot hole 25 mm, and a 6.5 mm hole 60 mm, beyond the rise's outside face. Mark the holes after bending.

**How it fits the parts next to it.** The run lies flat on the cleat's level leg, held by two M6 bolts with nyloc nuts; it points out at 47 degrees from the gable line, away from the house, to put the pod over the gutter's centre line 200 mm beyond its end (Figure 18). The pod plate lies on the tab (Figure 15). At 120 km/h the arm sees about 8 MPa, a nineteenth of its strength.

**Check before moving on.** With the run on a flat bench, the tab is level within 1 degree.

### 3.10 Verge cleats (make 2: a front and a back)

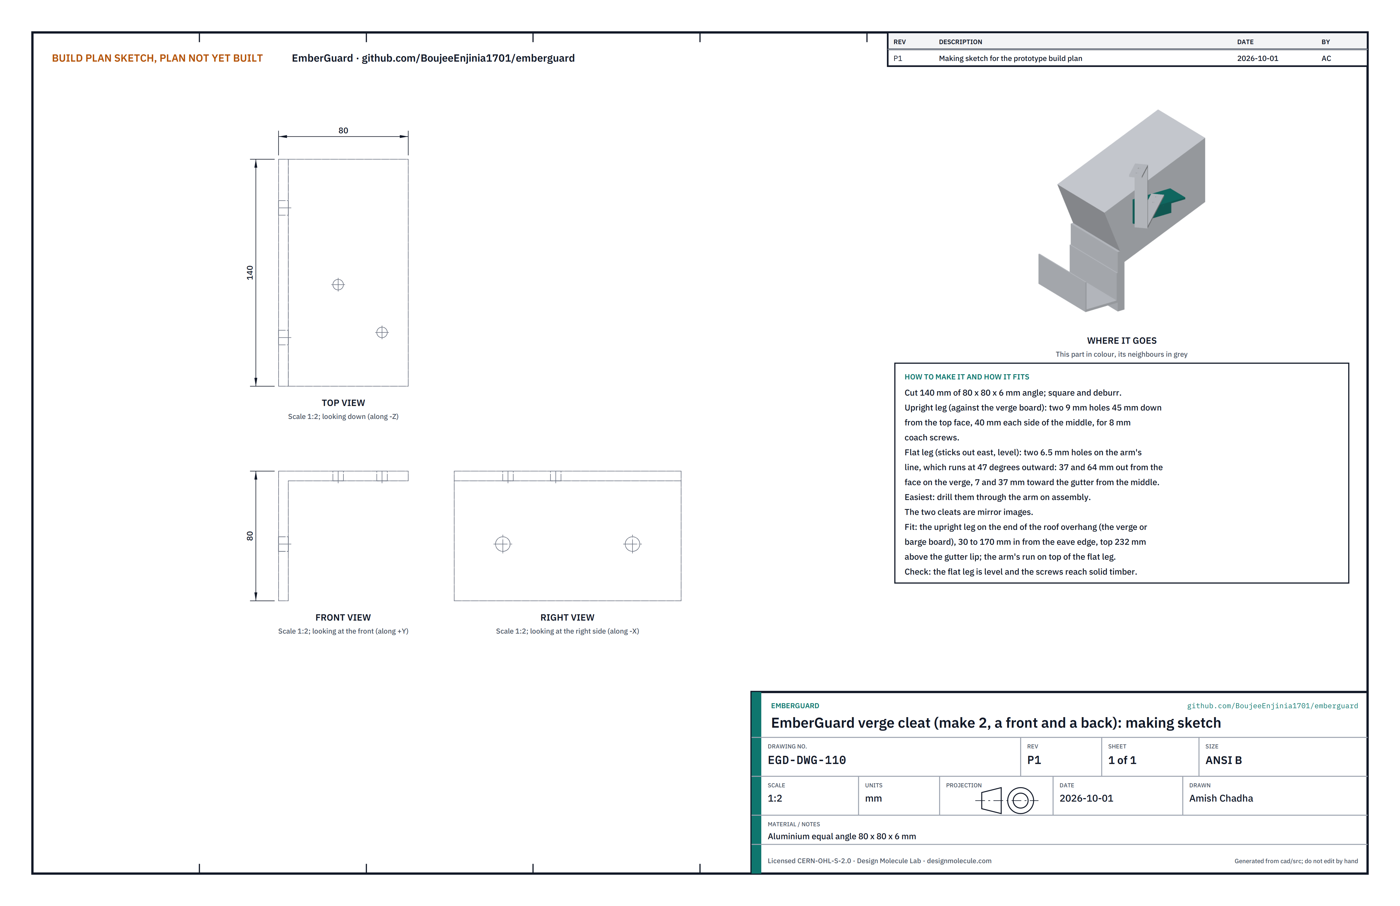
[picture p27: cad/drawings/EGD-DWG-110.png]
Figure 17. Making sketch of the verge cleat


*Figure 17. Verge cleat making sketch (EGD-DWG-110).*

**What it is and what it is made from.** The angle that fixes each pod arm to the end of the roof overhang. Aluminium equal angle 80 x 80 x 6 mm, 140 mm long.

**How to make it.**

1. Cut two 140 mm lengths; square and deburr.
2. Upright leg: two 9 mm holes 45 mm down from the top face, 40 mm each side of the middle, for 8 mm coach screws.
3. Level leg: two 6.5 mm holes on the arm's line, 37 and 64 mm out from the face on the verge, 7 and 37 mm toward the gutter from the middle. It is easiest to clamp the arm in place and drill through it.

**How it fits the parts next to it.**

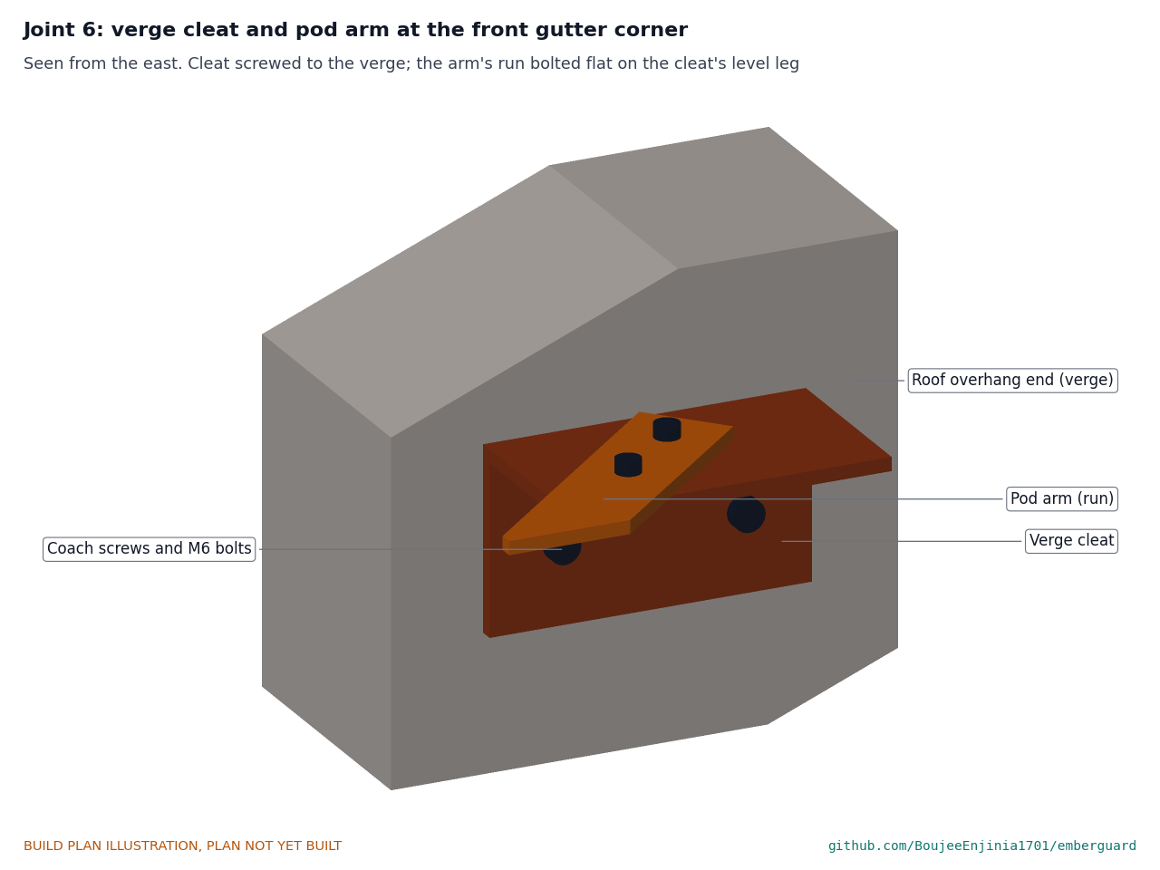
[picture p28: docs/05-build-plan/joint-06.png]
Figure 18. Joint 6: cleat and arm at the front gutter corner


*Figure 18. The cleat screwed to the verge; the arm's run bolted flat on its level leg, clear of the roof, fascia and gutter.*

The upright leg lies flat on the end face of the roof overhang (the verge or barge board), between 30 and 170 mm in from the eave edge, its top 232 mm above the gutter lip, held by two 8 mm x 80 mm coach screws into solid timber. The level leg sticks out east. Nothing touches the fascia or the gutter.

**Check before moving on.** The level leg is level; each coach screw pulls tight into timber, not into the roof covering.

### 3.11 Ground enclosure, drilled

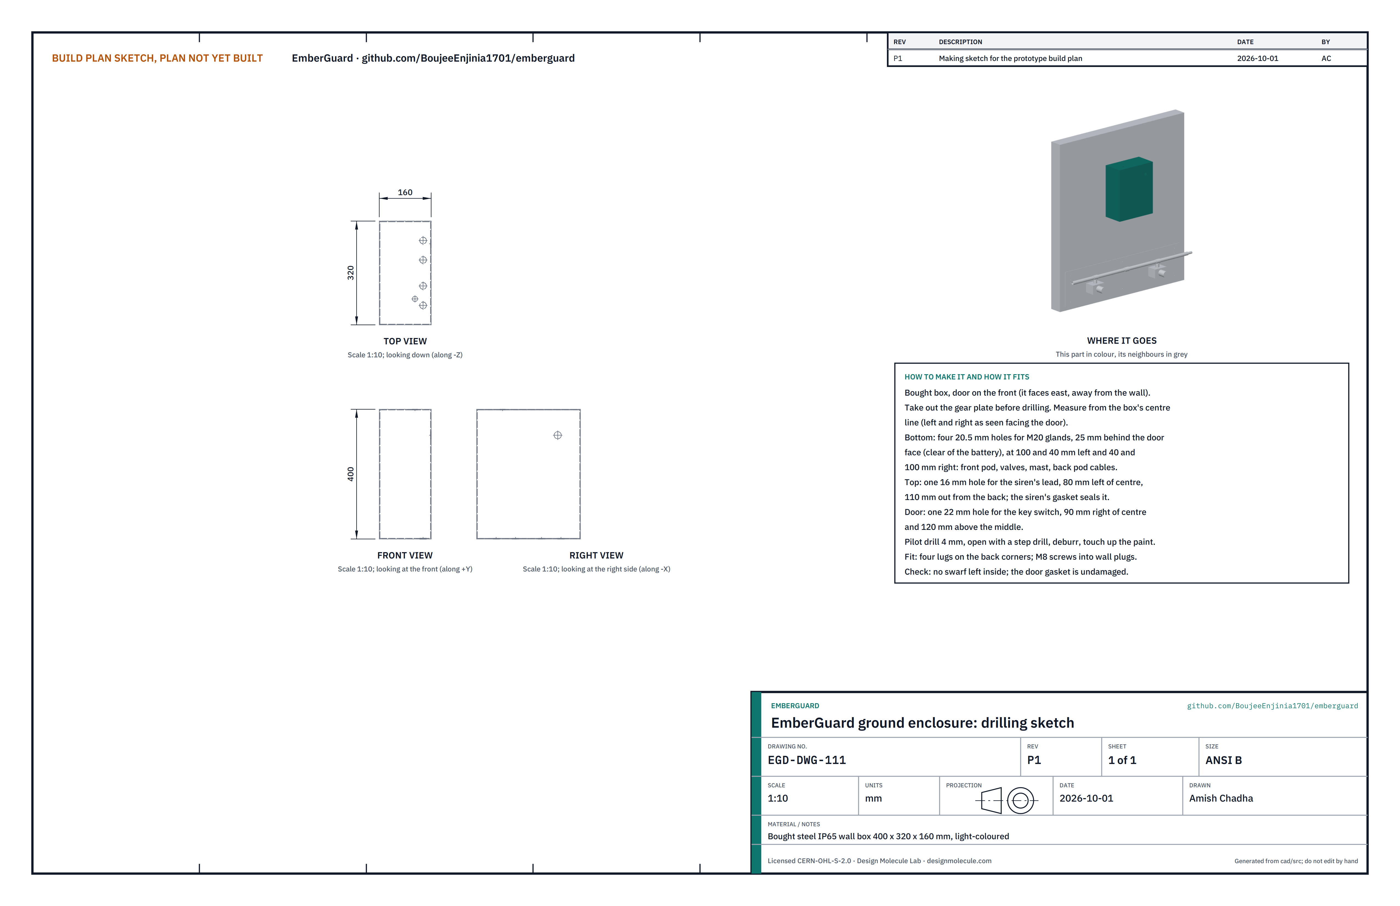
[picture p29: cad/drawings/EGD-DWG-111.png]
Figure 19. Drilling sketch of the ground enclosure


*Figure 19. Ground enclosure drilling sketch (EGD-DWG-111).*

**What it is and what it is made from.** A bought steel IP65 wall box, 400 tall, 320 wide and 160 deep, light-coloured, fixed on the shadiest wall available, with a gasketed door on the front, a gear plate on four studs inside the back and four wall lugs.

**How to make it.**

1. Take out the gear plate. Mark holes from the box's vertical centre line, left and right as seen facing the door.
2. Bottom: four 20.5 mm holes for M20 glands, 25 mm behind the door face, at 100 and 40 mm left and 40 and 100 mm right of centre: front pod, valves, mast and back pod cables.
3. Top: one 16 mm hole for the siren's lead, 80 mm left of centre and 110 mm out from the back.
4. Door: one 22 mm hole for the key switch, 90 mm right of centre and 120 mm above the middle.
5. Pilot drill 4 mm, open out with a step drill, deburr and touch up the paint on every edge.

**How it fits the parts next to it.**

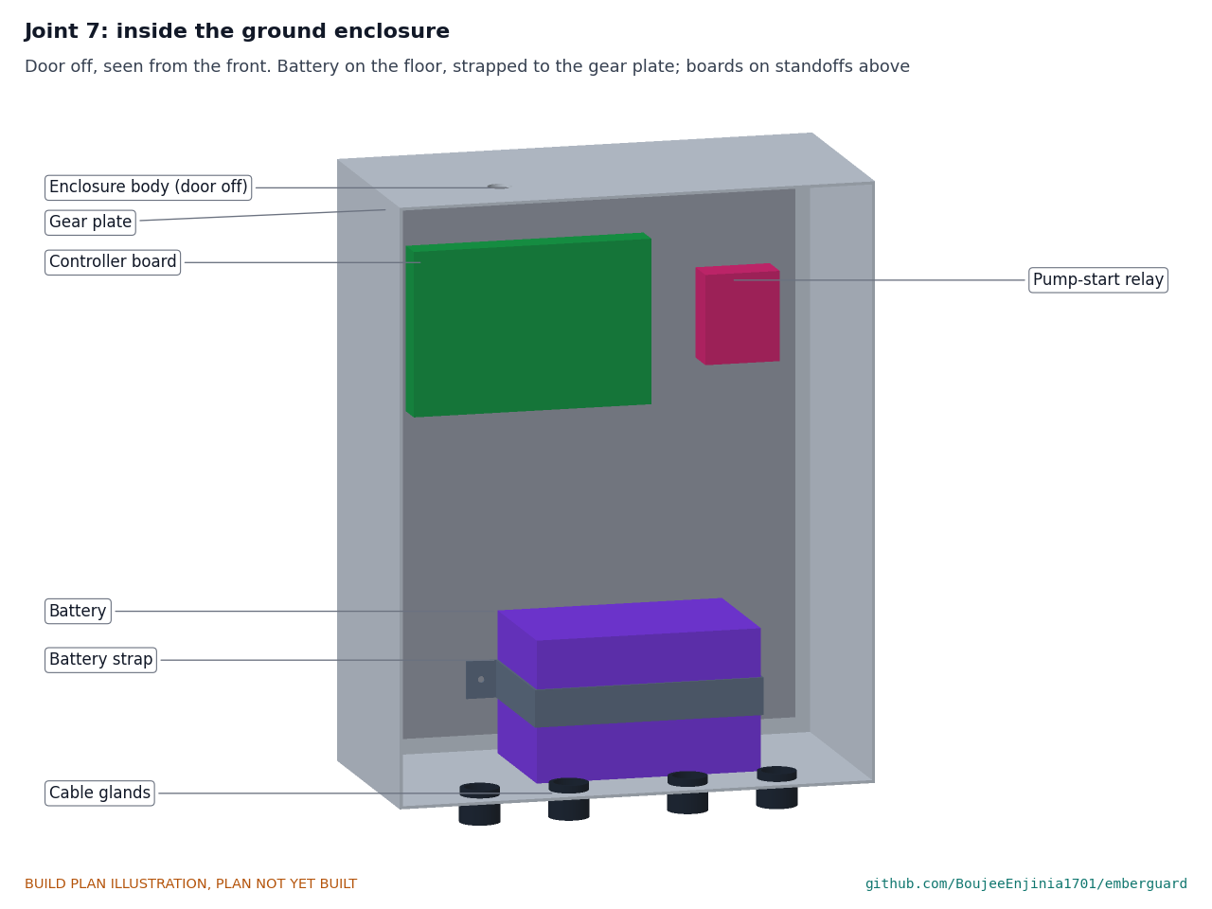
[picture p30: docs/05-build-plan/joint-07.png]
Figure 20. Joint 7: inside the enclosure


*Figure 20. The battery stands on the floor against the gear plate, held by the strap; the controller and relay stand on standoffs on the gear plate above it.*

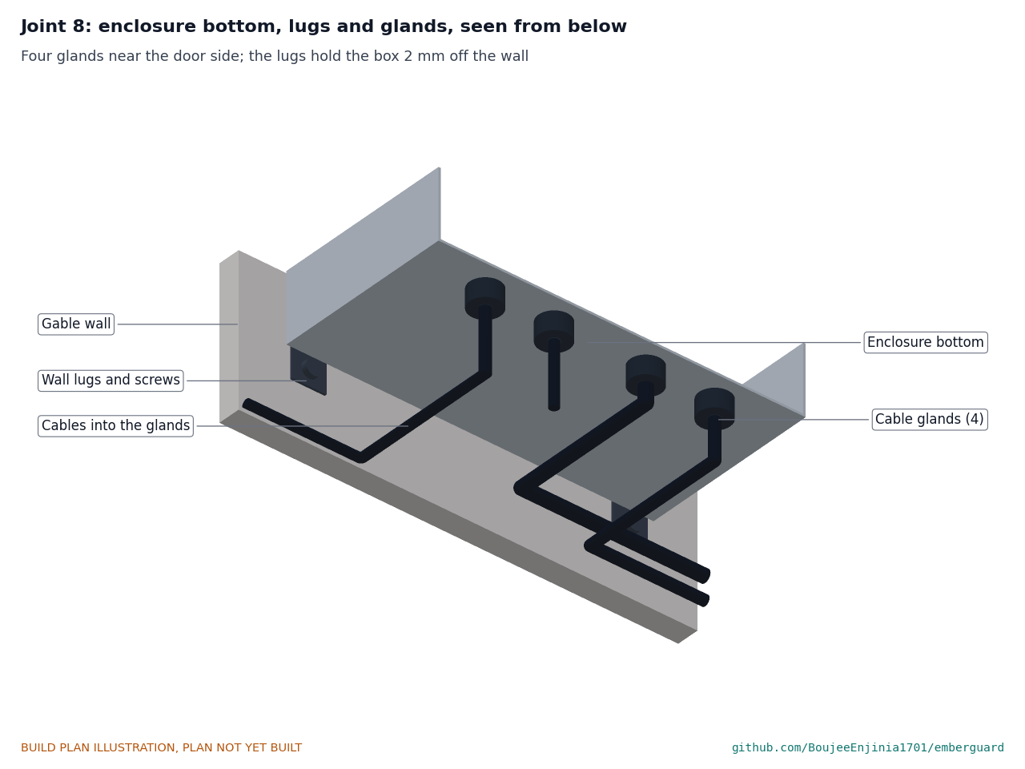
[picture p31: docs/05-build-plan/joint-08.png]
Figure 21. Joint 8: enclosure bottom, lugs and glands


*Figure 21. Four glands near the door side of the floor; the lugs hold the box 2 mm off the wall.*

The four lugs bolt to the back corners and stand 25 mm above and below the box; each takes an M8 screw into a wall plug. The gear plate goes back on its studs with the controller board (on four 10 mm standoffs) and the relay (on two) fitted to it. The battery stands on the floor against the gear plate, held by the strap 50 mm above the floor. The siren sits on the top on its own gasket; the key switch goes through the door.

**Check before moving on.** No swarf inside; the door closes evenly on its gasket; the battery cannot move when pushed.

#### 3.11.1 Wiring

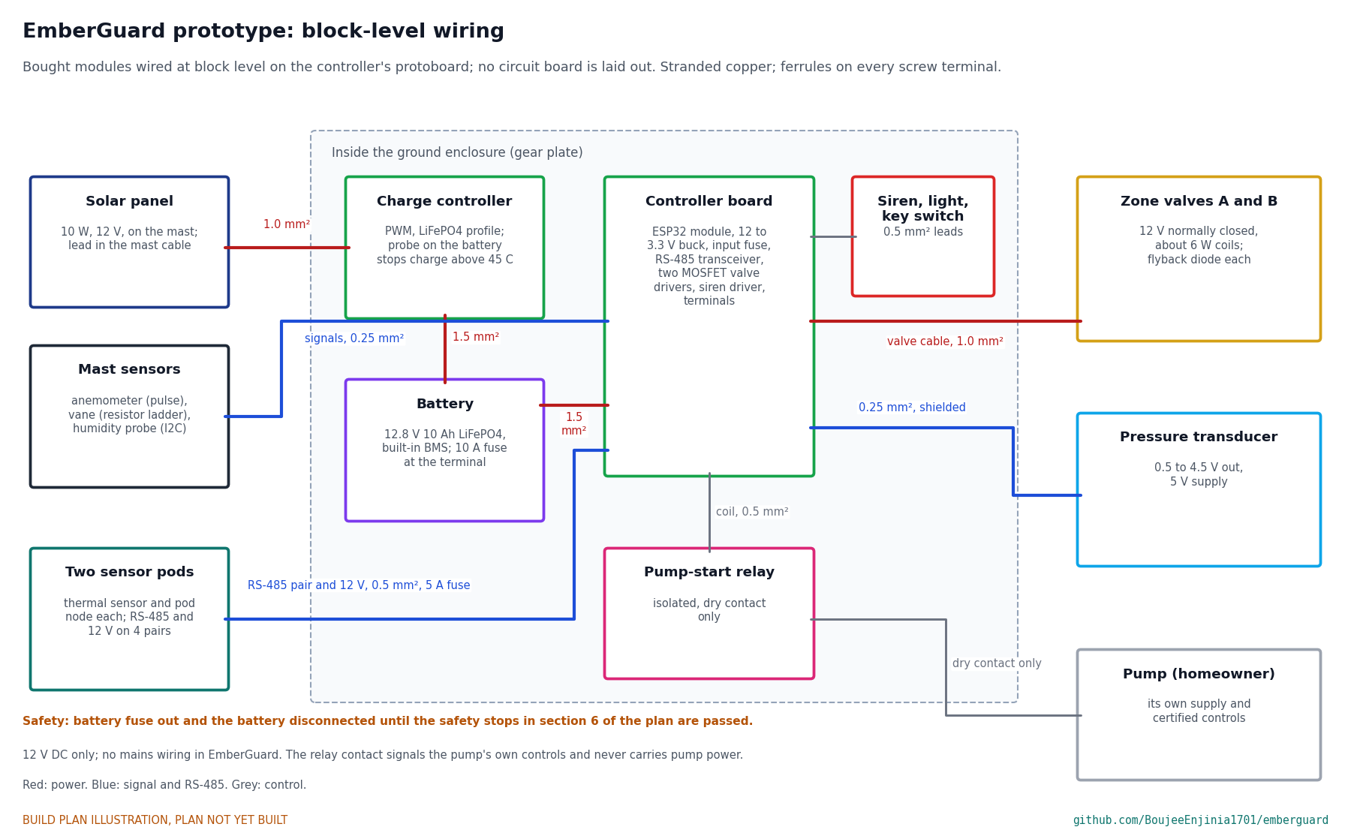
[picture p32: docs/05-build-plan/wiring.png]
Figure 22. Block-level wiring


*Figure 22. Block-level wiring with wire sizes. No circuit board is laid out at this stage; bought modules on a protoboard stand in for the controller.*

The controller is a protoboard carrying bought modules, which is enough for this prototype; a laid-out board is TRL 4 work. Wire it like this, with stranded copper and a ferrule on every screw terminal:

1. Panel lead (in the mast cable) to the charge controller's panel input: 1.0 mm².
2. Charge controller to the battery, and battery to the controller board, through the 10 A fuse at the battery terminal: 1.5 mm².
3. Wind, vane and humidity signals (in the mast cable) to the controller: 0.25 mm².
4. Each pod cable to the controller: the RS-485 pair as 0.25 mm² twisted pair, and 12 V and ground at 0.5 mm² through a 5 A fuse for both pods.
5. Valve drivers to the two valve coils through the valve cable: 1.0 mm², with a flyback diode across each coil.
6. Transducer to the controller: 0.25 mm², shielded, 5 V supply.
7. Controller to the relay coil, siren, status light and key switch: 0.5 mm².
8. Relay contacts to the pump's own control input: dry contact only, in a separate cable.

**Check before moving on.** Every wire continues end to end; with the battery fuse out, every rail reads open to ground; every wire is labelled.

### 3.12 Battery strap

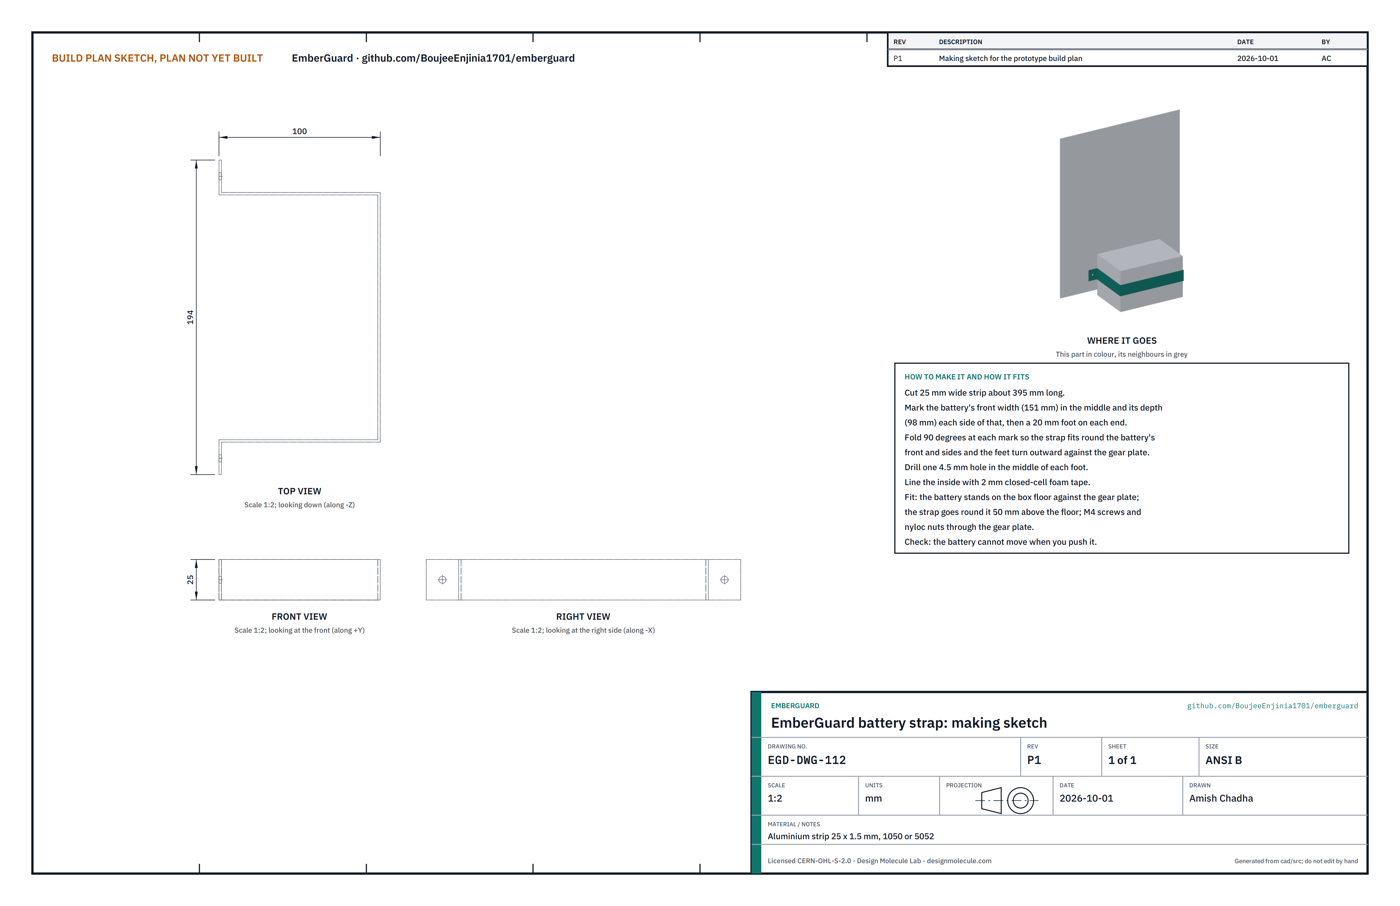
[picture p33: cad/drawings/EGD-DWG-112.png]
Figure 23. Making sketch of the battery strap


*Figure 23. Battery strap making sketch (EGD-DWG-112).*

**What it is and what it is made from.** The band that holds the battery against the gear plate. Aluminium strip 25 x 1.5 mm.

**How to make it.**

1. Cut about 395 mm of strip.
2. Mark the battery's front width (151 mm) in the middle, its depth (98 mm) each side of that, and a 20 mm foot on each end.
3. Fold 90 degrees at each mark so the strap fits round the front and sides and the feet turn outward.
4. Drill a 4.5 mm hole in the middle of each foot and line the inside with 2 mm closed-cell foam tape.

**How it fits the parts next to it.** The feet lie flat on the gear plate, 50 mm above the box floor, on two M4 screws with nyloc nuts (Figure 20).

**Check before moving on.** The strap holds the battery snug without denting its case.

### 3.13 Valve board

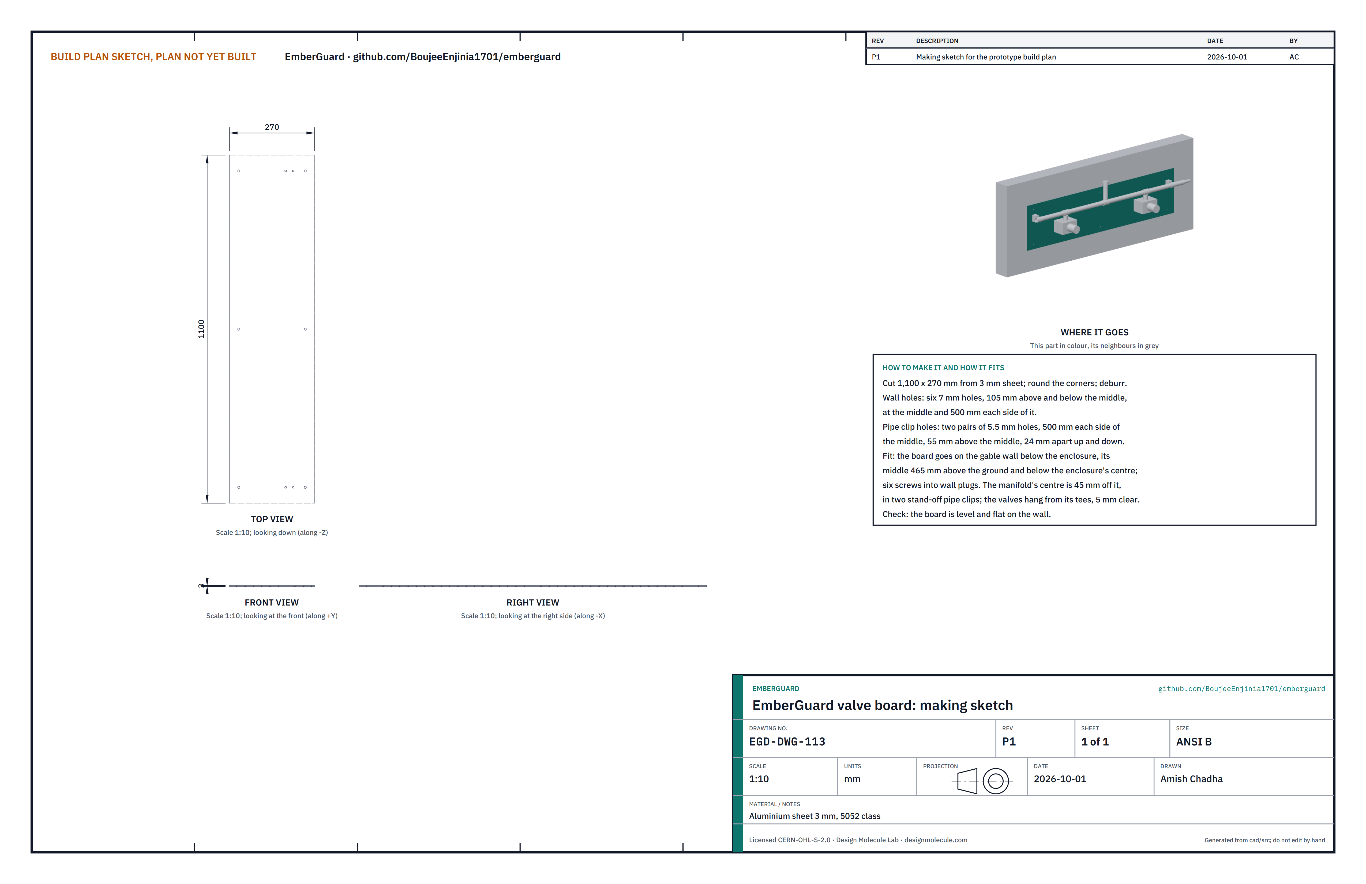
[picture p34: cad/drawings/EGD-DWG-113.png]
Figure 24. Making sketch of the valve board


*Figure 24. Valve board making sketch (EGD-DWG-113).*

**What it is and what it is made from.** The plate on the gable wall that carries the manifold, valves and transducer. Aluminium sheet 3 mm, 5052 class, 1,100 x 270 mm.

**How to make it.**

1. Cut the blank, round the corners and deburr.
2. Wall holes: six 7 mm holes, 105 mm above and below the middle, at the middle and 500 mm each side of it.
3. Pipe clip holes: two pairs of 5.5 mm holes, 500 mm each side of the middle, 55 mm above the middle, 24 mm apart up and down.

**How it fits the parts next to it.**

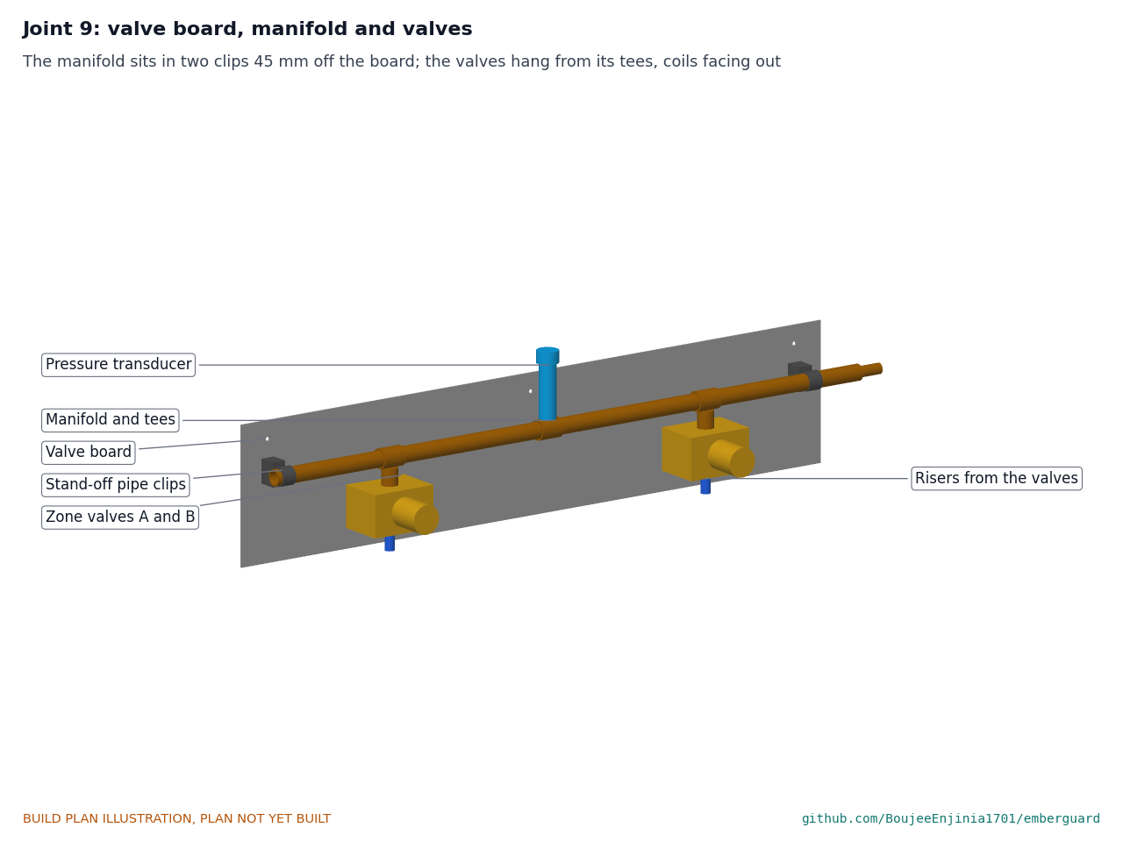
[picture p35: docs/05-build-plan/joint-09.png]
Figure 25. Joint 9: valve board, manifold and valves


*Figure 25. The manifold sits in two stand-off pipe clips; each valve hangs from its own tee, coil facing out; the transducer stands on the middle tee.*

The board's middle is 465 mm above the ground, directly below the enclosure. The manifold's centre is 45 mm off the board and 520 mm above the ground, in two stand-off pipe clips. Valve A (front zone) hangs from the tee 300 mm toward the front eave of the enclosure's centre line, valve B 300 mm toward the back; water flows down through each. The supply hose connects to the manifold's end toward the back eave.

**Check before moving on.** The board is level and flat on the wall; every threaded joint has sealant.

### 3.14 Spray lines (cut from the roll)

**What it is and what it is made from.** 16 mm UV-stable polyethylene line, cut to length on site: 17.5 m for the front zone and 21.1 m for the back, each with an end plug, two elbows at the eave corner and six tees for the heads.

**How it fits the parts next to it.**

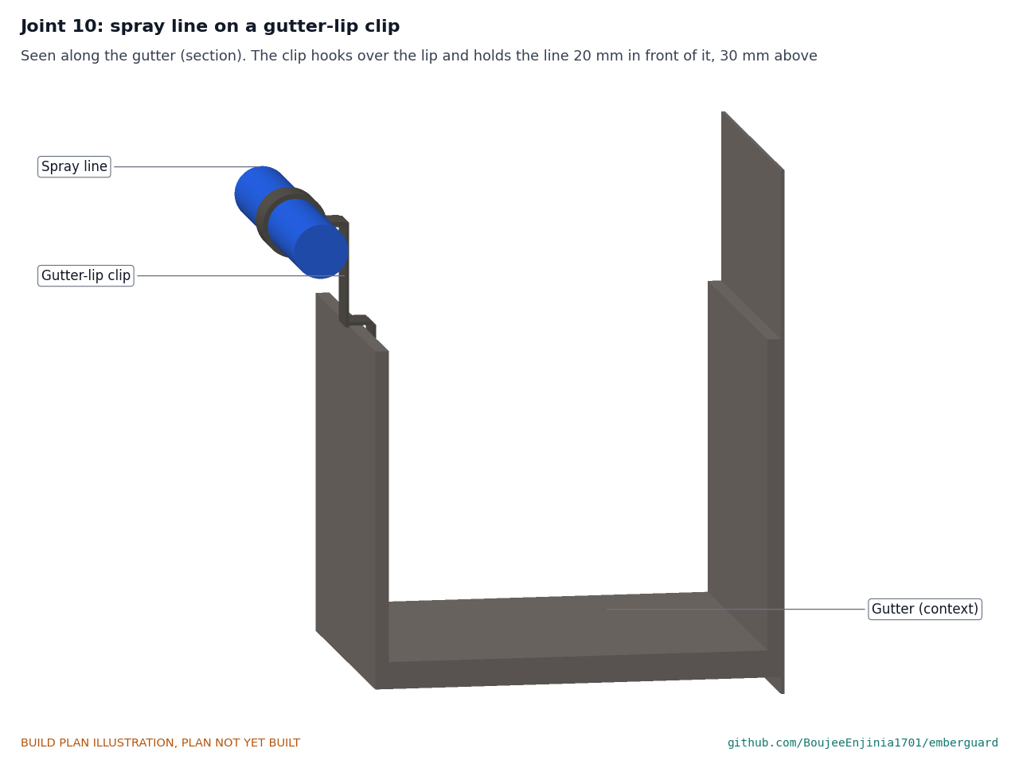
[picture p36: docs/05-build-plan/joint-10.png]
Figure 26. Joint 10: spray line on a gutter-lip clip


*Figure 26. The clip hooks over the gutter lip and holds the line 20 mm in front of it and 30 mm above it.*

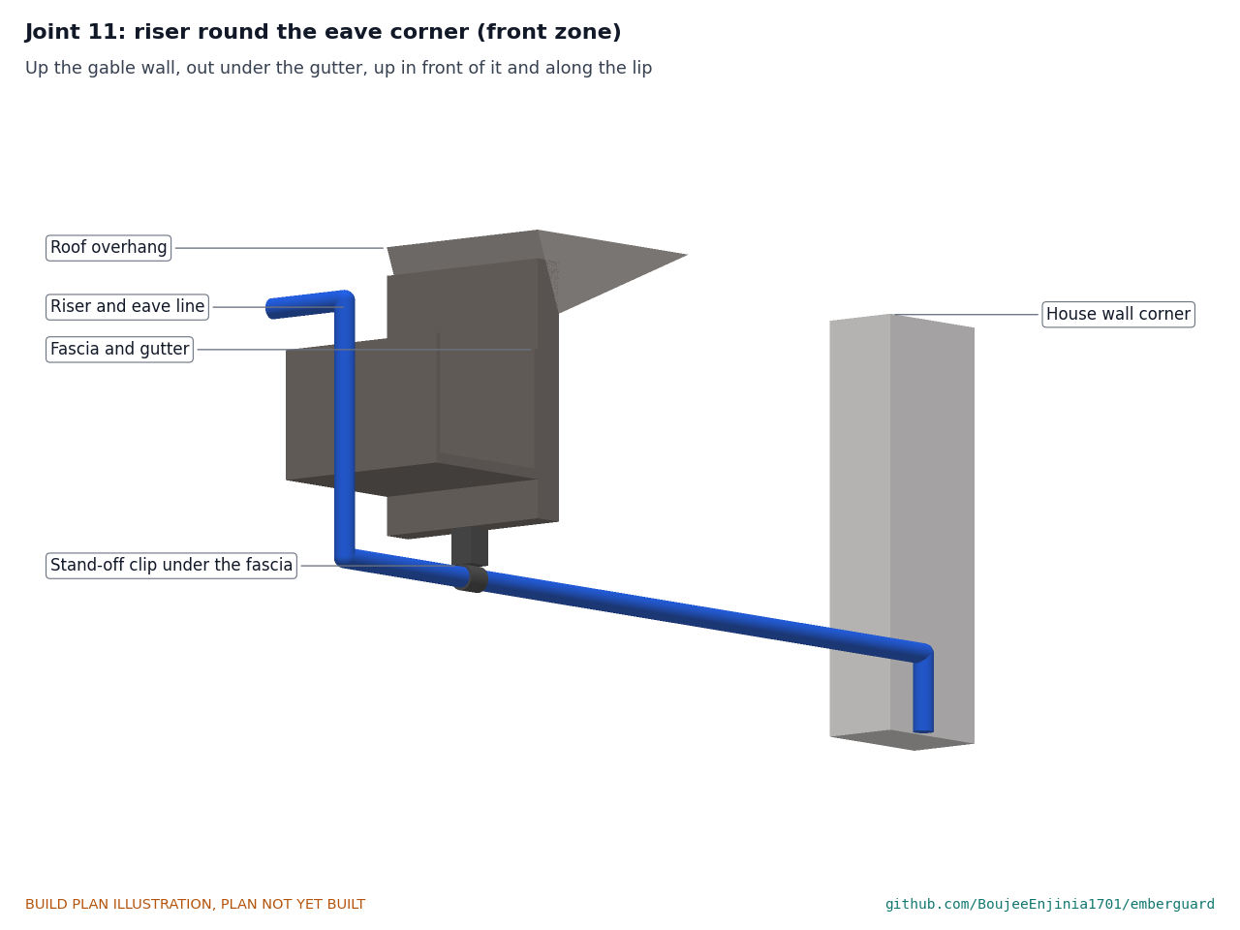
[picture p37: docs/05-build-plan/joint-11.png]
Figure 27. Joint 11: riser round the eave corner


*Figure 27. Up the gable wall, out under the gutter on a stand-off clip at the fascia, up in front of the gutter and along the lip.*

From its valve each riser bends back to the wall, runs along the base of the gable wall 250 mm above the ground in saddle clips every 600 mm, and turns up the wall 25 mm in from the corner, with a clip every 500 mm. At 2.30 m it turns out under the eave, passes 30 mm under the fascia (one stand-off clip screwed into the fascia's lower edge holds it) and 8 mm in front of the gutter, rises to 30 mm above the lip and turns along the gutter. The eave run sits in 12 gutter-lip clips per eave, one 450 mm each side of every head. The heads push onto tees at 2.2 m spacing, 1.1 m, 3.3 m and 5.5 m each side of the house's middle, pointing up.

**Check before moving on.** The line is supported at every clip and does not touch the gutter anywhere.

### 3.15 Sun shade (make 1)

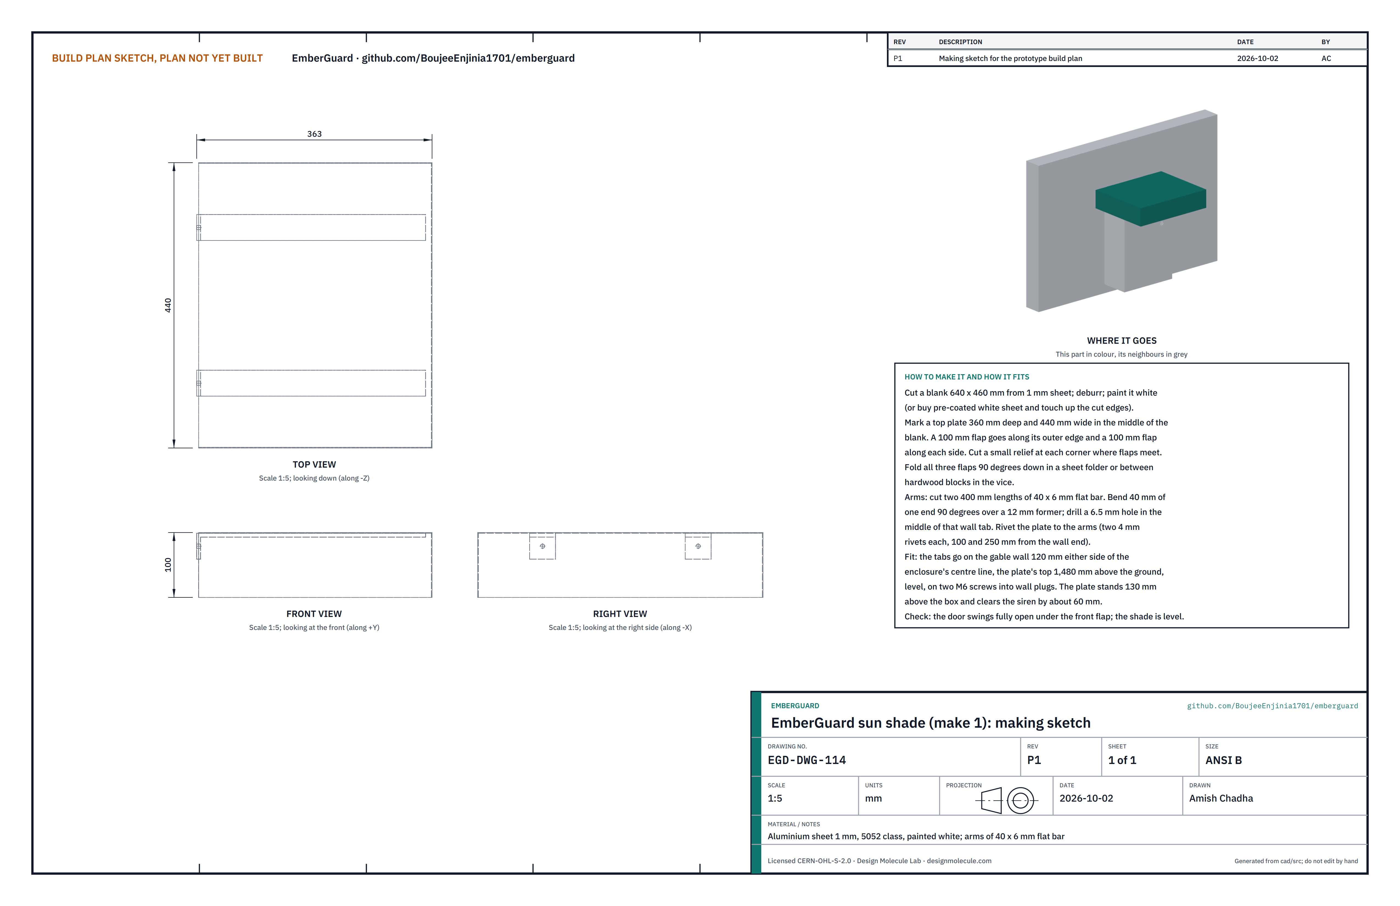
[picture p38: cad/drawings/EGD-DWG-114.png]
Figure 28. Making sketch of the sun shade


*Figure 28. Sun shade making sketch (EGD-DWG-114).*

**What it is and what it is made from.** A folded white sheet that shades the top of the ground enclosure and the upper part of its door, on two flat-bar arms bolted to the gable wall. The sheet is 1 mm aluminium, 5052 class, painted white; the arms are 40 x 6 mm flat bar, 6063-T6, the same stock as the pod arms. It keeps the battery cooler in fire weather.

**How to make it.**

1. Cut a blank 640 x 460 mm from the sheet and deburr it. Paint it white, or buy white pre-coated sheet and touch up the cut edges.
2. Mark a top plate 360 mm deep and 440 mm wide in the middle of the blank, with a 100 mm flap along its outer edge and a 100 mm flap along each side. Cut a small relief at each corner where flaps meet.
3. Fold the three flaps 90 degrees down in a sheet folder, or between hardwood blocks in the vice.
4. Cut two 400 mm lengths of flat bar. Bend 40 mm of one end 90 degrees over a 12 mm former and drill a 6.5 mm hole in the middle of that wall tab.
5. Rivet the plate to the arms with two 4 mm rivets each, 100 and 250 mm from the wall end.

**How it fits the parts next to it.** The tabs go on the gable wall 120 mm either side of the enclosure's centre line, with the top of the plate 1.48 m above the ground and level, on two M6 screws into wall plugs. The plate stands 130 mm above the enclosure and about 60 mm above the siren, and projects about 200 mm past the door. In a 120 km/h gust it can lift with up to 108 N, so use plugs and screws good for at least 500 N in the wall material.

**Check before moving on.** The plate is level; the door swings fully open under the front flap; the siren is clear of the plate; the paint is not cracked at the folds.

### 3.16 Bought components

Buy to specification, not brand. Line numbers are those of the bill of materials.

- **Mast tube, pipe, flanges and U-bolts (line 1).** 40 x 2 mm 6061-T6 tube; DN25 galvanized pipe; two slip-on base flanges for 33.7 mm tube with set screws and four holes on an 80 mm circle; four M8 U-bolts for 40 mm tube and four for 33.7 mm pipe, stainless, with nyloc nuts; eight M10 wall anchors suited to the wall.
- **Pod parts (line 2).** Die-cast aluminium box about 100 x 80 x 70 mm, 4 mm walls; pod node board (small microcontroller and RS-485 transceiver); M16 cable gland; four 15 mm M4 aluminium spacers; two 8 mm x 80 mm coach screws, M6 and M8 stainless bolts.
- **Thermal sensors (line 3).** MLX90640 BAB (55 x 35 degree lens) on a breakout of 25 x 25 mm or less with the can centred and corner holes, with a 9.5 mm O-ring.
- **Wind and humidity sensors (lines 4 and 5).** Weather-station cup anemometer and vane with a crossarm and mast-top sleeve; SHT4x-class probe in a five-plate shield with a mast clamp.
- **Enclosure (line 7).** Steel IP65 wall box about 400 x 320 x 160 mm, light-coloured, with a gear plate on studs and four wall lugs.
- **Controller, battery, panel and relay (lines 6, 8, 9 and 12).** ESP32-class module, MOSFET valve drivers, RS-485 transceiver, 12 to 3.3 V buck and fuses on a protoboard; 12.8 V 10 Ah LiFePO4 with built-in BMS and low-temperature charge cut-off; 10 W 12 V panel with a pole-mount tilt bracket and a PWM charge controller with a LiFePO4 profile and a battery temperature probe that stops charging above 45 °C; isolated 10 A dry-contact relay module.
- **Valves and transducer (lines 10 and 11).** Two 12 V DC normally closed DN20 solenoid valves of zero-minimum-pressure type, inlet and outlet in line; a 0 to 10 bar, 0.5 to 4.5 V transducer.
- **Cables (line 13).** 10 m of shielded 4-pair outdoor cable for the mast, 6 m and 10 m for the pods, 2 m twin for the valves, 1 m silicone heat sleeve at each pod.
- **Spray line (line 14).** 50 m of 16 mm UV-stable polyethylene, 12 micro-sprinklers of about 40 L/h at 2 bar, 24 gutter-lip clips, elbows, tees and end plugs.
- **Siren (line 15).** 12 V piezo siren about 100 dB with status light, keyed arm switch.
- **Fittings (line 16).** Manifold pipe with three tees and a hose connector, two stand-off pipe clips, saddle clips, two stand-off clips for the fascia, four M20 glands, wall plugs and screws, cable ties, fuse holders and fuses.
- **Earthing (line 17).** 1.2 m copper-clad earth rod with clamp, 6 m of 16 mm² green-yellow conductor, mast bonding clamp.
- **Sun shade (line 18).** Sheet for a 640 x 460 mm blank of 1 mm aluminium, white paint, 800 mm of 40 x 6 mm flat bar, two M6 screws with plugs, four 4 mm rivets.

## 4. Putting it together

In each picture the parts already fitted are grey and the parts being fitted are in colour, with an arrow showing the way they go in. Steps 1 to 10 are bench work (the sun shade of section 3.15 is also made on the bench); steps 11 to 18 are on the house.

**Site notes.** Gutter guards are not part of the kit. Where leaves or needles collect deep in a gutter, the homeowner fits guards of non-combustible mesh before step 16, below the gutter lip so the lip clips and spray line still fit. Guards keep deep fuel out of the gutter. The calculations assume an open gutter (EGD-CAL-001, section A), and what the sensors see over a guard has not been checked.

### Step 1: flange onto each wall plate

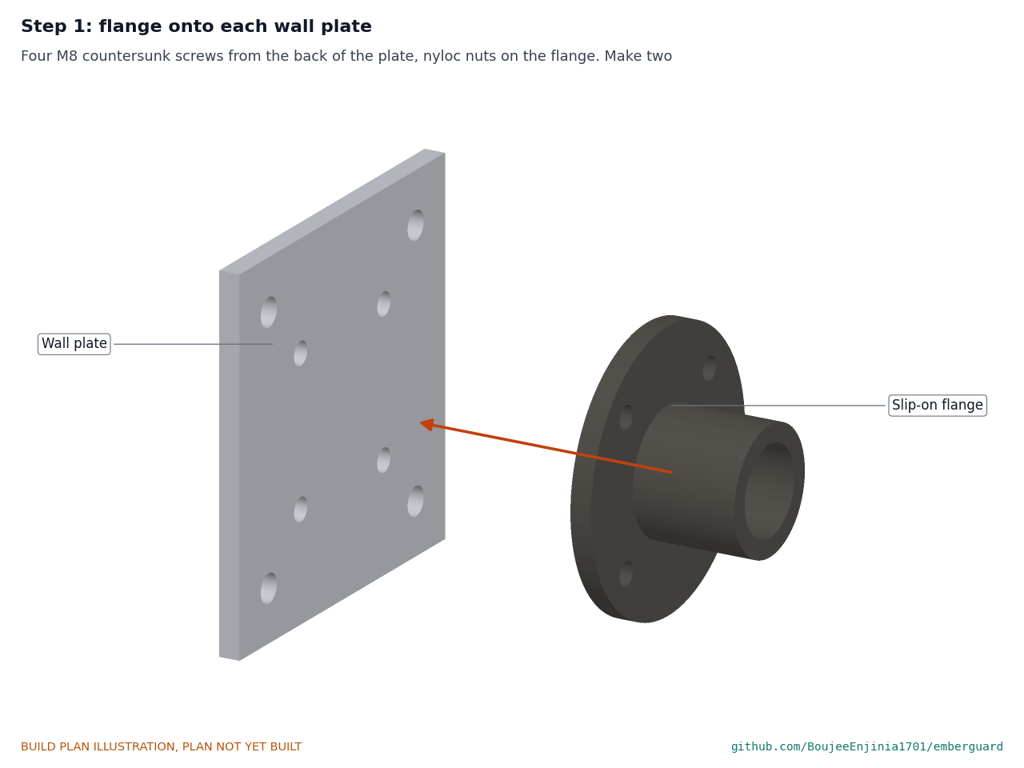
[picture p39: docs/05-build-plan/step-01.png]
Step 1


Four M8 countersunk screws from the back of the plate, nyloc nuts on the flange, tight. Make two.

### Step 2: end cap and wind sensors on the mast

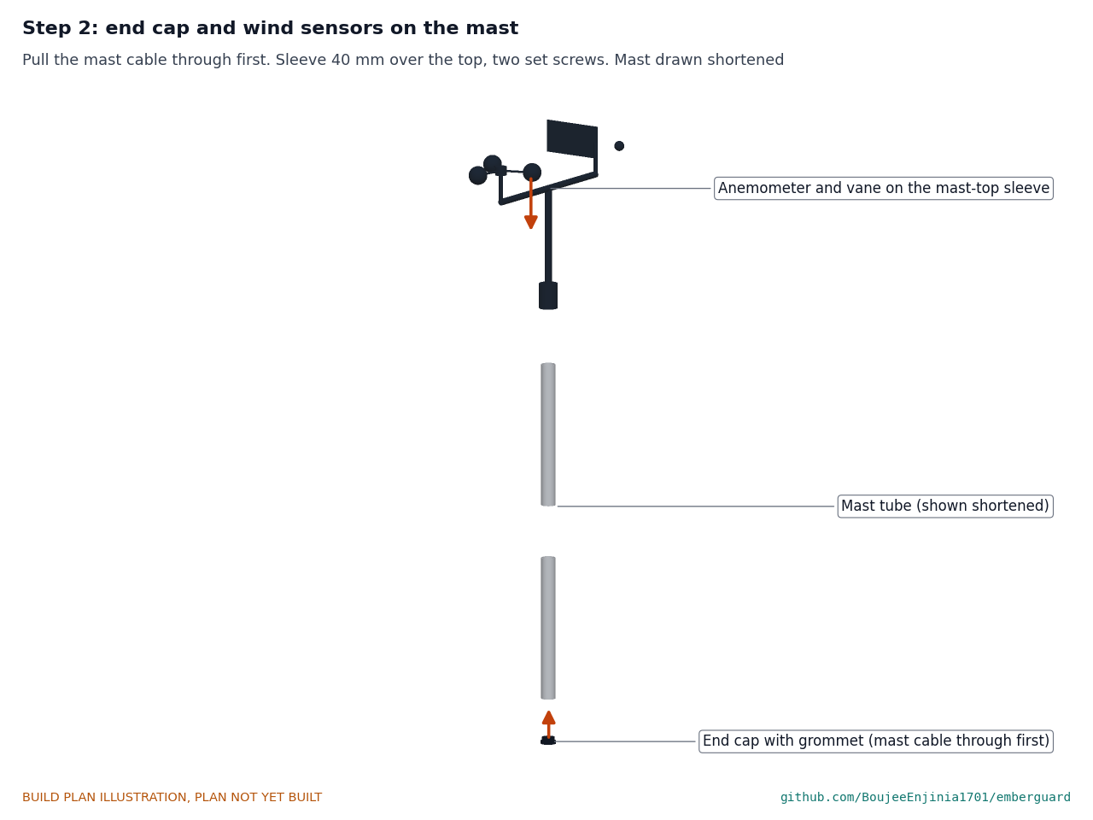
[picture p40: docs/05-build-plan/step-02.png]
Step 2


With the mast cable already pulled through (section 3.4), push the end cap into the foot. Slide the wind sensors' sleeve 40 mm over the top and tighten its two set screws; connect the wind sensors to the cable.

### Step 3: humidity shield and solar panel onto the mast

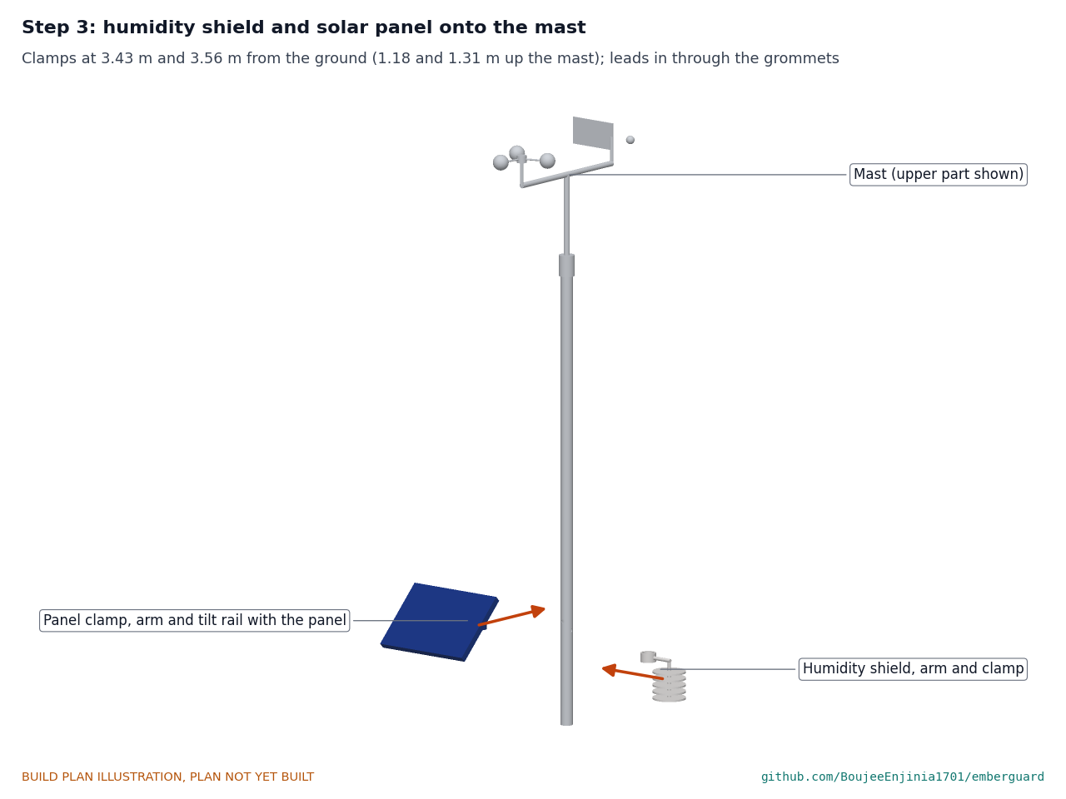
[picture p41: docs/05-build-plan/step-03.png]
Step 3


Humidity shield clamp centred 1,175 mm up the tube, arm pointing east; panel clamp centred 1,310 mm up, arm pointing toward the equator. Set the panel to 45 degrees with an angle finder and tighten. Feed both leads into their grommets.

### Step 4: sensor, node board and lens hood into the pod

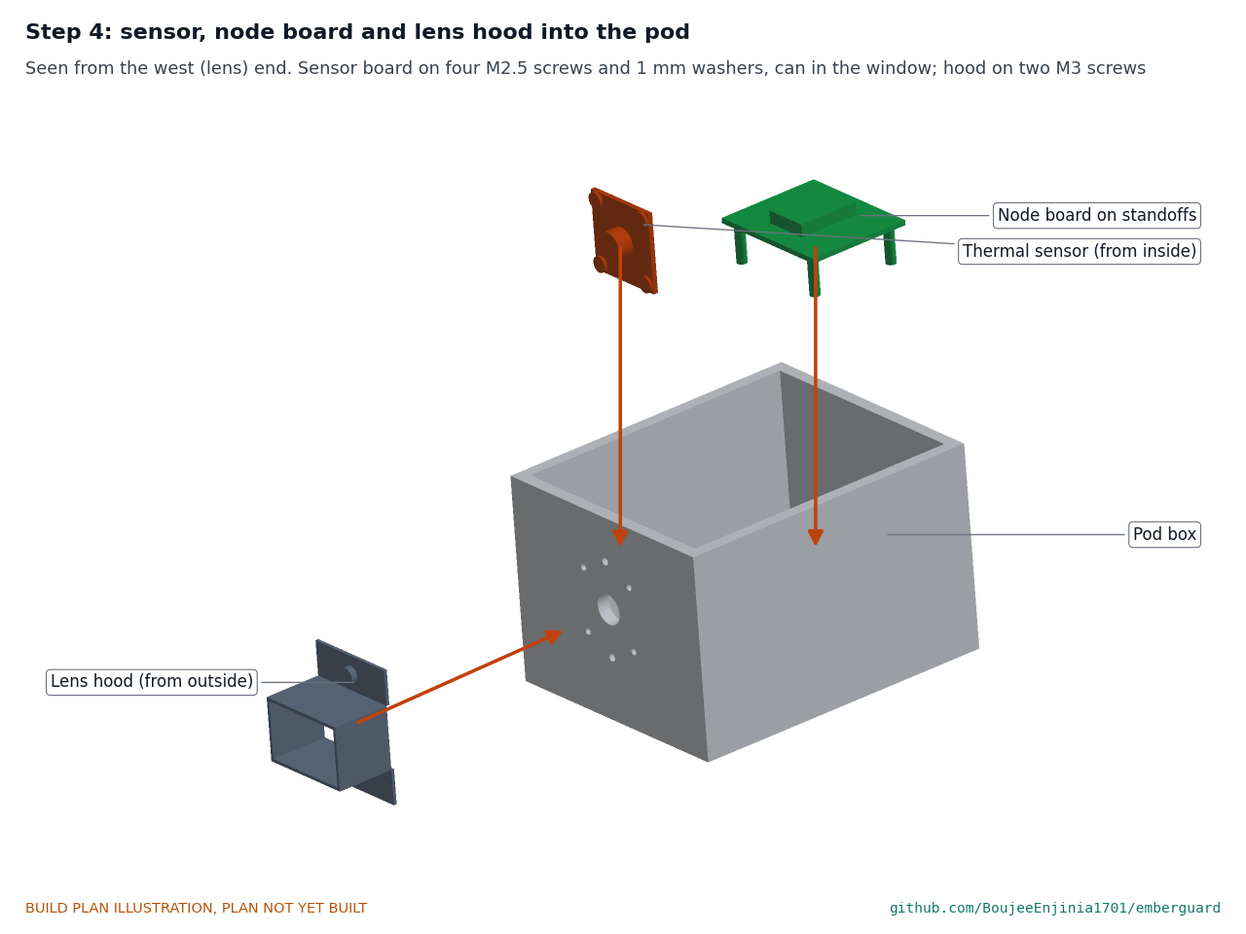
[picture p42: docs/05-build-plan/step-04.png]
Step 4


Sensor board inside the west wall on four M2.5 screws over 1 mm nylon washers, O-ring round the can, can in the window. Node board on its four standoffs. Lens hood outside on two M3 screws. Connect the sensor to the node board.

### Step 5: cable gland, lid and hood on the pod

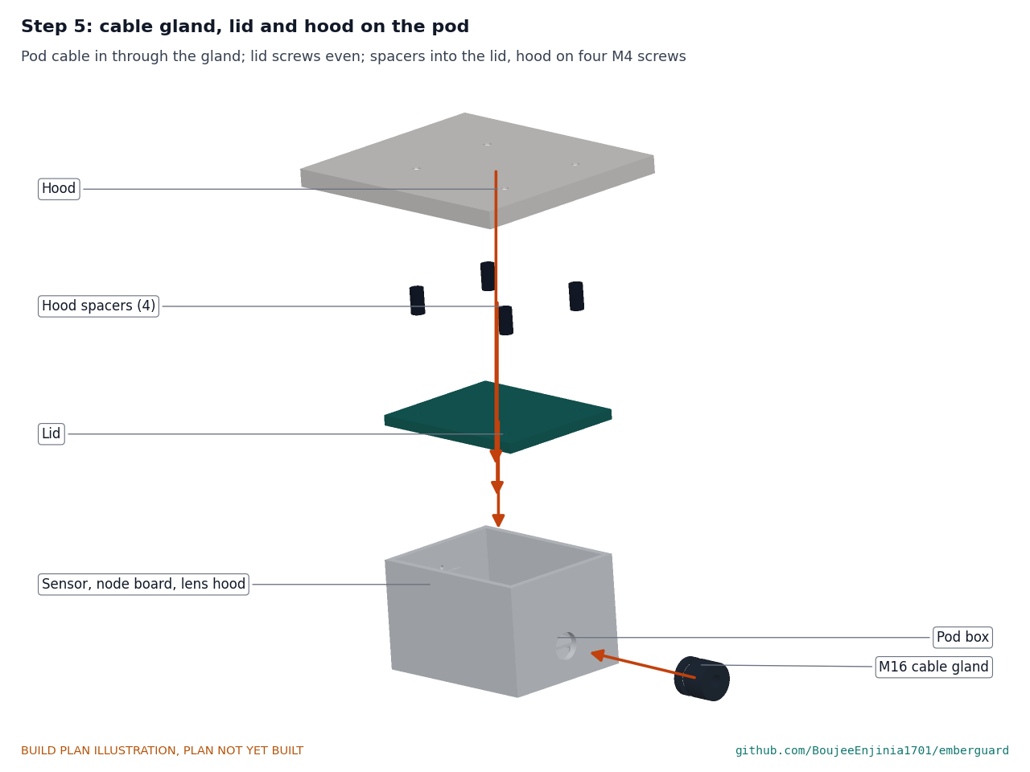
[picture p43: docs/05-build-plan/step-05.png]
Step 5


Pod cable in through the M16 gland and onto the node board's terminals; tighten the gland. Lid on, screws tightened evenly. Spacers into the lid, hood on them with four M4 screws.

### Step 6: pod plate under the pod

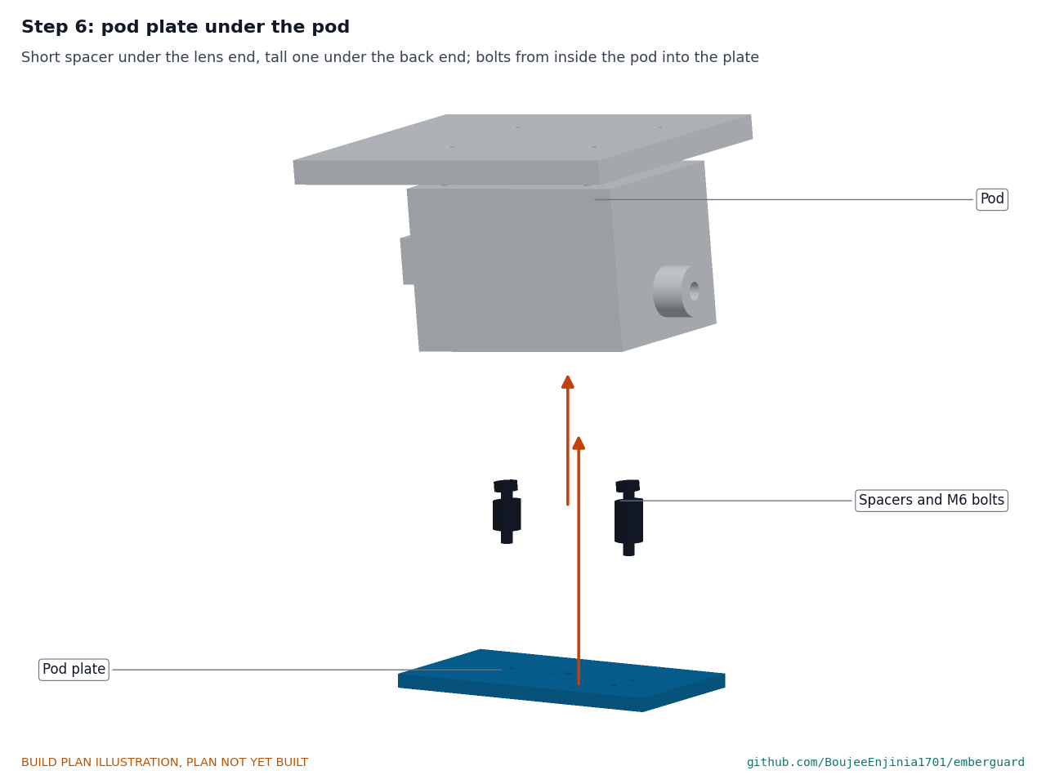
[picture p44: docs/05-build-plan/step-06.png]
Step 6


Two M6 bolts from inside the pod, through the floor (sealing washers), through the short spacer under the lens end and the tall one under the other end, into the plate's tapped holes. **Hold point:** the pod reads 5 degrees nose down on the lid.

### Step 7: arm onto the cleat

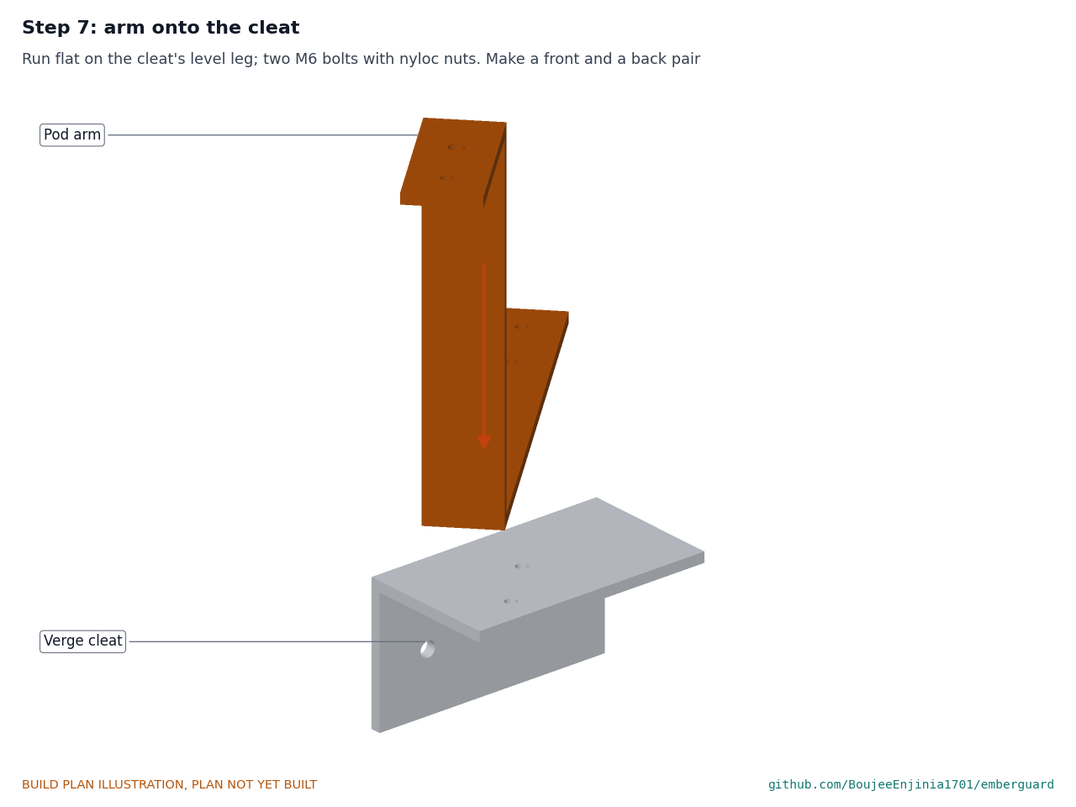
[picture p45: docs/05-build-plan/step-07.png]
Step 7


The run lies flat on the cleat's level leg; two M6 bolts with nyloc nuts. Make a front pair and a back pair; they are mirror images.

### Step 8: lugs, glands, siren and key switch on the enclosure

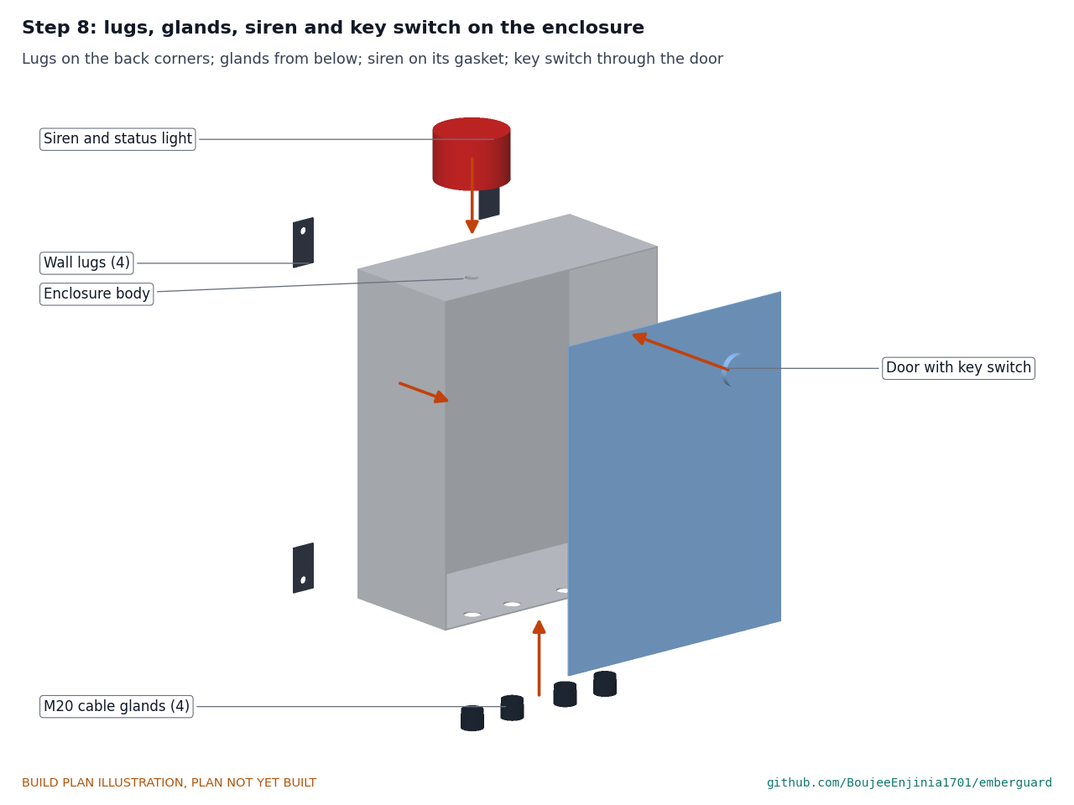
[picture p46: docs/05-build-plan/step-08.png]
Step 8


Lugs on the four back corners as the box maker describes. Glands from below, nuts inside. Siren on the top on its gasket. Key switch through the door from the front, nut inside.

### Step 9: gear plate, controller, relay and battery into the enclosure

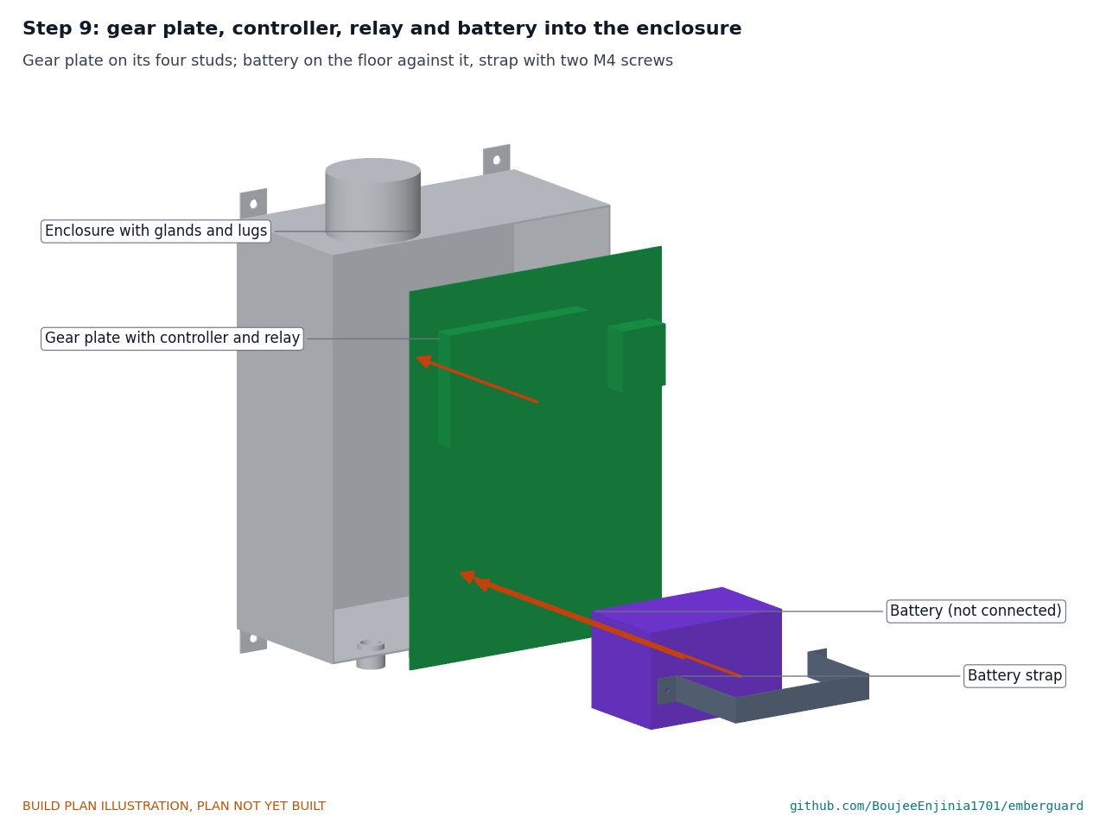
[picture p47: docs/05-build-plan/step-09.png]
Step 9


Gear plate on its four studs with the controller and relay already on it. Battery on the floor against the plate, strap round it on two M4 screws. Wire as section 3.11.1. **Hold point:** battery fuse out (section 6, S3).

### Step 10: clips, manifold, valves and transducer on the valve board

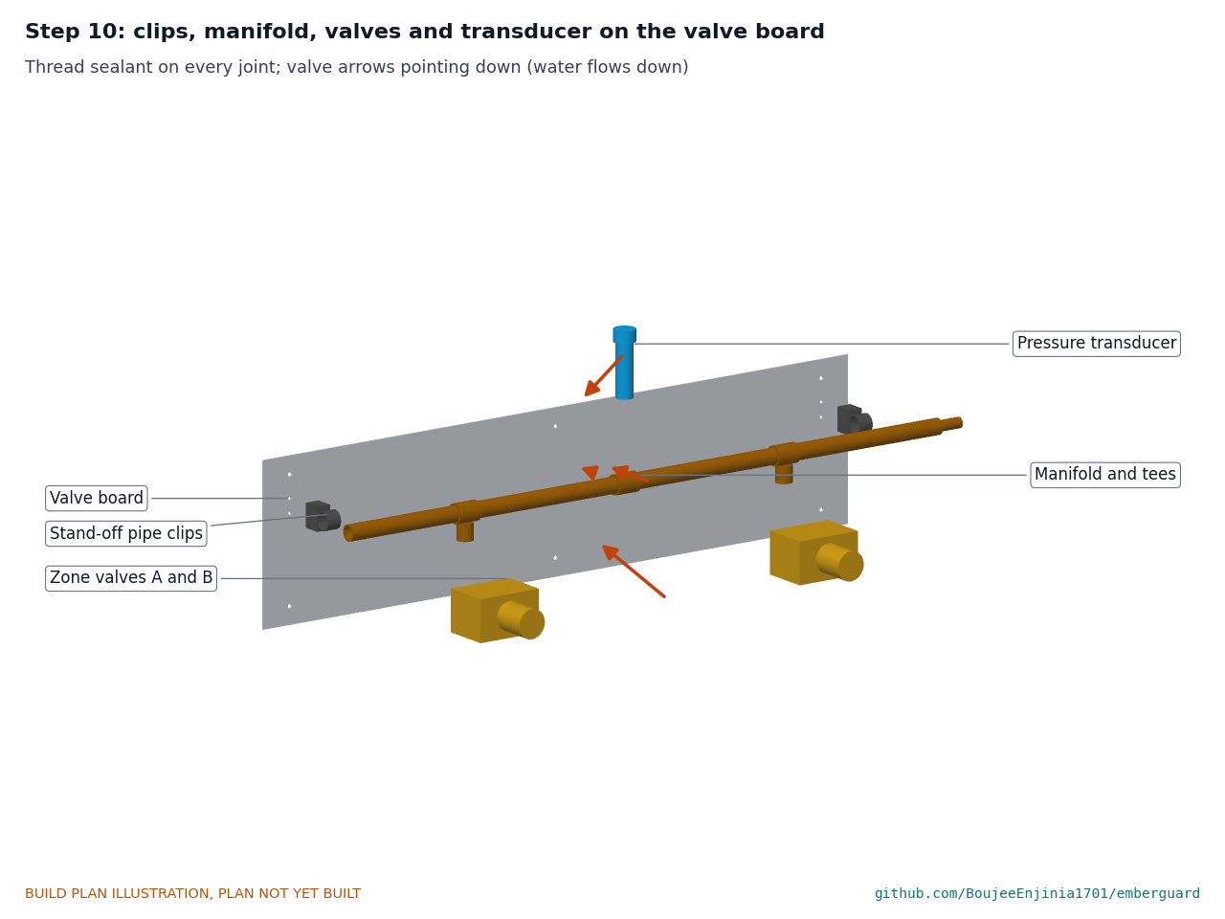
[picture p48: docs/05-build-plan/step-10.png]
Step 10


Two stand-off pipe clips on the board. Manifold into the clips with its three tees pointing down, down and up. Valves onto the down tees, flow arrows pointing down, coils facing out. Transducer onto the up tee. Thread sealant on every threaded joint.

### Step 11: wall plates and standoffs on the gable wall

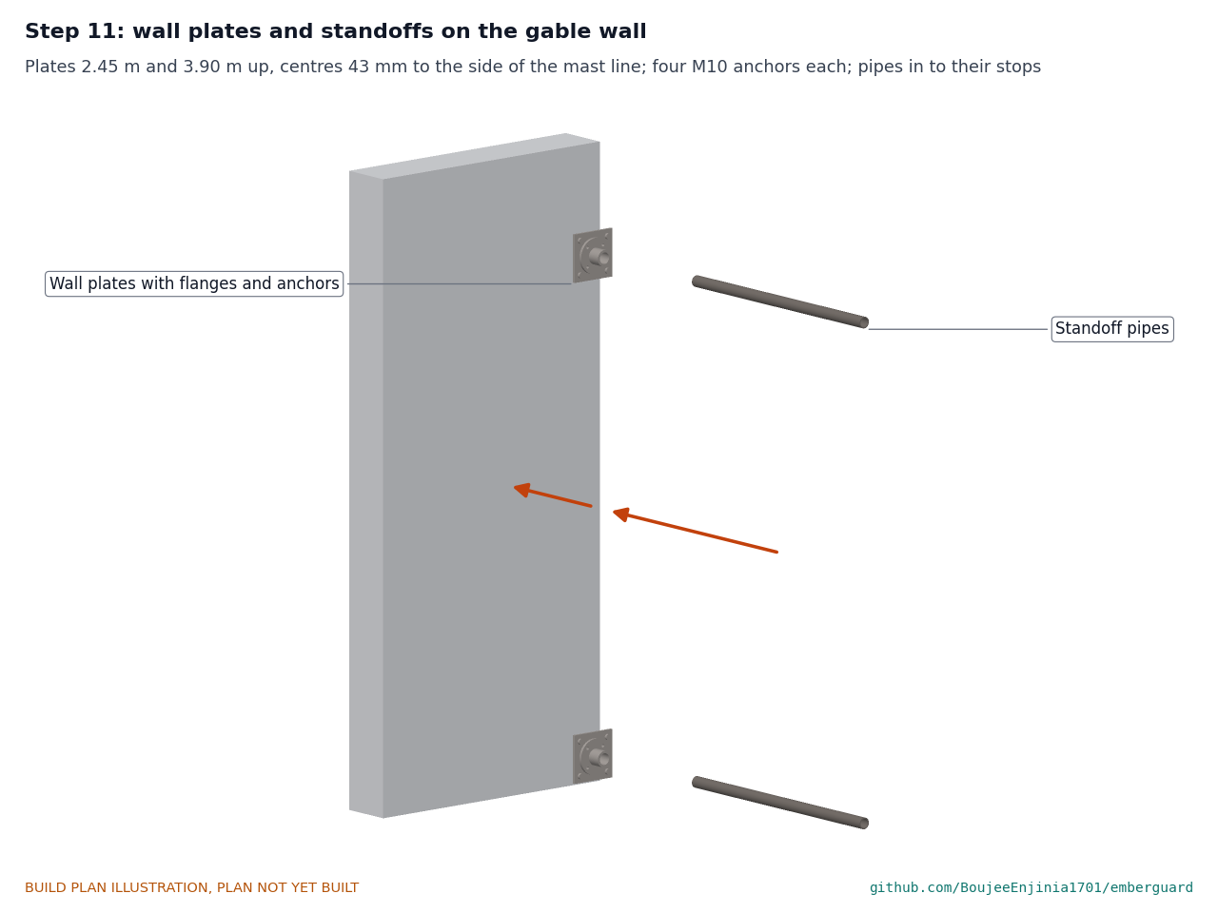
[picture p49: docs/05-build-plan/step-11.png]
Step 11


Mark the mast's line (the ridge line) on the gable wall. Plates centred 43 mm to the back-eave side of it, 2.45 m and 3.90 m up, square and level; four M10 anchors each. Standoffs into the flanges to their stops, set screws tight, outer ends level. **Hold point:** safety stops S1 and S2.

### Step 12: mast onto the standoffs

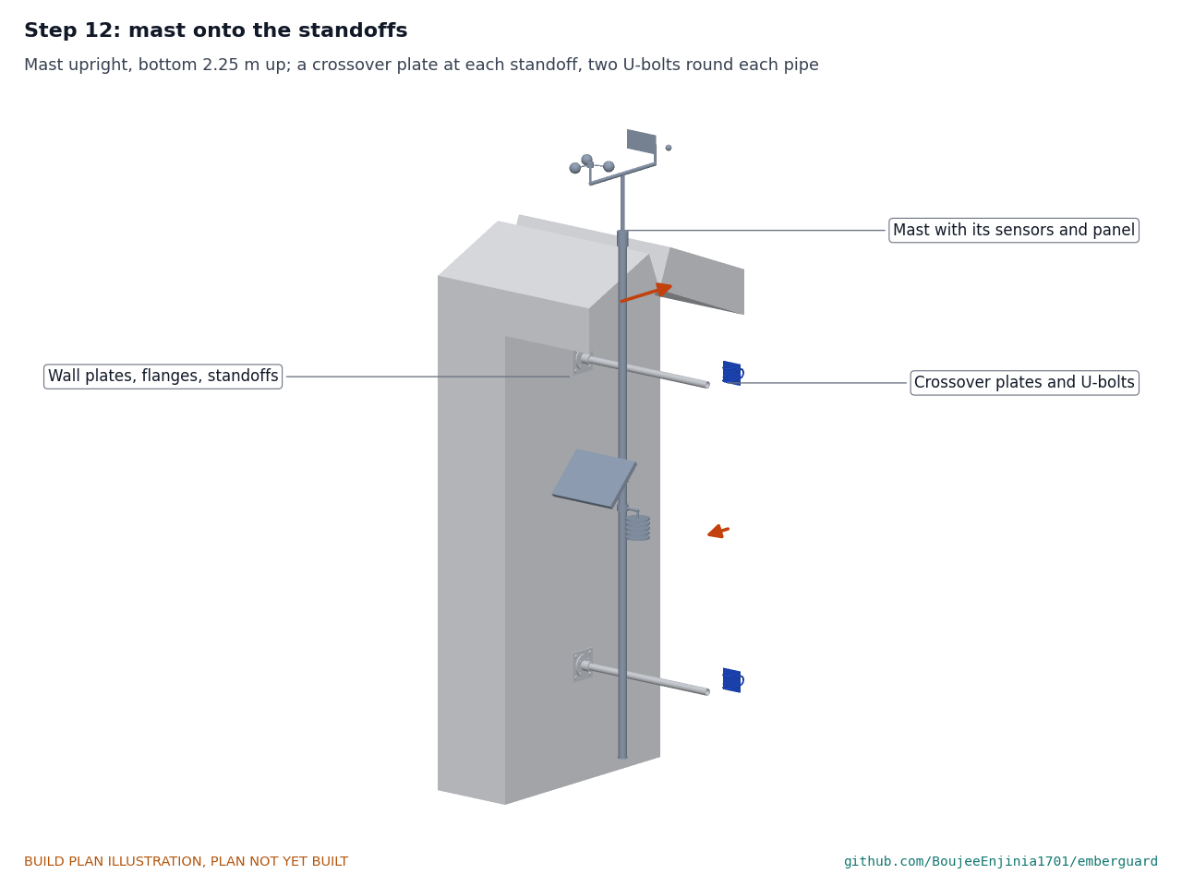
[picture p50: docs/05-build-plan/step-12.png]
Step 12


With a helper holding the mast upright, its foot 2.25 m above the ground, hang a crossover plate at each standoff and fit the four U-bolts at each, nuts finger tight. Plumb the mast with a level in two directions, then tighten all nuts evenly.

### Step 13: earth the mast

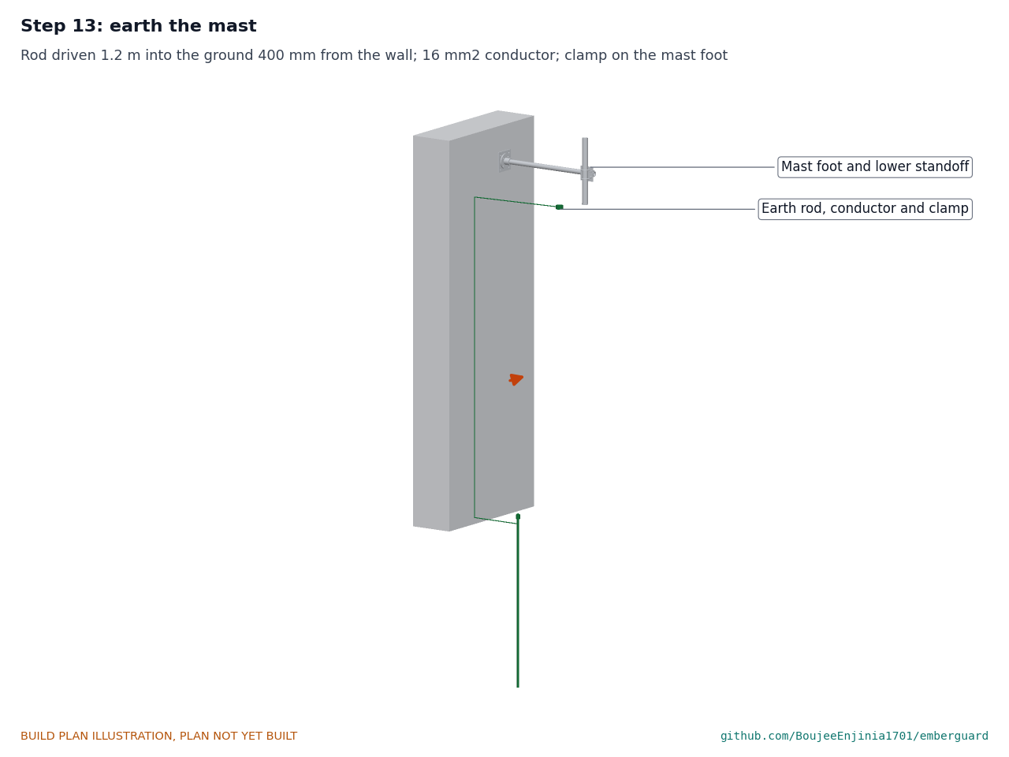
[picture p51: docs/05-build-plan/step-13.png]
Step 13


Drive the rod into the ground 400 mm out from the wall, below the mast, leaving 120 mm above ground. Bonding clamp on the mast foot, 25 mm up. Conductor from the clamp to the wall, down it 40 mm off the wall on stand-off clips, and to the rod's clamp. **Hold point:** safety stop S4.

### Step 14: cleat, arm and pod at each gutter corner

Step 14

Hold the cleat with its arm on the verge, upright leg flat, level leg level, 30 to 170 mm in from the eave edge. Drill 5 mm pilot holes and drive the two coach screws. Put the pod's plate on the tab with the pivot bolt, swing the pod until it points along the gutter and 10 degrees toward the house (sight along the lens hood's side to a mark on the gutter 8 m away), and lock the slot bolt. Repeat at the other gutter.

### Step 15: enclosure and valve board on the gable wall

Step 15

Enclosure on the shadiest wall available (the plan shows the east gable wall), centred 1.15 m above the ground, 1.8 m toward the front eave from the mast's line, level; four M8 screws into wall plugs through the lugs. Valve board below it, middle 465 mm above the ground; six screws into wall plugs. Connect the supply hose. **Hold point:** safety stop S2 before every wall hole.

### Step 16: spray lines

Step 16

For each zone: from the valve, along the wall base on saddle clips, up the corner, out under the gutter through the fascia clip, up in front of the gutter, and along the lip in the lip clips to the far end. Tees and heads at their marks; end plug at the far end. Flush the line before fitting the end plug.

### Step 17: cables into the enclosure

Step 17

Mast cable from the mast foot, under the lower standoff, down the wall; each pod cable along its arm, round the verge, under the soffit and down the gable corner; valve cable from the enclosure to the valves. Each through its own gland in the enclosure floor; saddle clips every 500 mm; the silicone heat sleeve over each pod cable for its first metre. Connect as section 3.11.1. **Hold point:** safety stops S3, S5 and S6.

### Step 18: sun shade over the enclosure

Step 18

Hold the shade's arms against the wall 120 mm either side of the enclosure's centre line with the top of the plate 1.48 m above the ground; check it is level and clear of the siren. Mark, drill and plug two holes, and fix the tabs with two M6 screws. Open the enclosure door fully to confirm it clears the front flap. **Hold point:** safety stop S2 before every wall hole.

## 5. First checks

These are the checks a TRL 4 test report would record; this plan only lists them. Requirement numbers are those of EGD-REQ-001.

*Table 2. First checks.*

| Check | Requirement | How | Pass when |
| --- | --- | --- | --- |
| Sensor view clear | R3 | Read a frame from each sensor with the pod on its arm; look at the image edges | No part of the lens hood, hood or arm in any pixel |
| Pod aim | R3 | Angle finder on the lid; sight along the hood's side | 5 degrees nose down and 10 degrees toward the house, each within 1 degree |
| Gutter in view | R3 | Hold a hand warmer in the open gutter at 1.5, 6 and 13 m from its east end | Seen at all three, in the expected pixels |
| Arming | R4 | Feed simulated wind pulses and humidity readings | Arms at 30 km/h sustained or 50 km/h gusts with humidity at or below 20 % for 10 min; key switch arms and disarms |
| Valves fail closed | R9 | Power each valve, then cut power | Opens when powered; closes within 1 s when power is lost |
| Joints hold pressure | R7 | Supply water at 2.5 bar with the heads plugged | No leak at any joint or valve |
| Flow per zone | R7 | Run each zone for 5 min into buckets | 4 L/min, give or take 10 % |
| Water to the farthest head | R5 | Time from opening the valve to water at the far head, at 4 L/min | 49 s or less, so that with 11 s for detection and the valve the total stays within 60 s (36 s and 43 s expected; 47 s and 54 s with the allowance) |
| Supply pressure | R7 | Transducer reading with one zone running | About 2.3 bar at the manifold |
| Fail to wet on sensor loss | R9 | Arm, then unplug a pod cable at the enclosure | Spraying starts and the alarm sounds |
| Alarms | R12 | Low battery (bench supply), no water (supply shut), faulty valve (coil unplugged) | Each raises the siren and status light |
| Battery and charging | R8 | Charge controller on its LiFePO4 profile; check the BMS cold cut-off with the pack below 0 °C; warm the controller's temperature probe above 45 °C | Charges to the pack maker's voltage; no charge below 0 °C or above 45 °C |
| Mast and pods steady | R10 | Push the mast top and each pod by hand | Nothing moves at any joint |
| Earth continuity | Safety | Resistance from the mast to the rod | As local practice requires (well under 1 ohm along the conductor) |
| Install time | R11 | Record the time for two people from step 11 to step 18 | 6 h or less |

## 6. Safety stops

Stop at each point. Carry on only when everything listed is true.

- **S1. Before any work at height.** Ladder on firm level ground, footed by a second person, tied or stood off at the roof edge; dry, calm weather with no thunder; nobody on the roof covering. Tools tied on.
- **S2. Before drilling into the wall or the verge.** The wall and verge are checked with a detector for cables, pipes and gas; the drill is on the right setting for the wall material; dust mask and eye protection on.
- **S3. Before the battery fuse goes in.** Every wire checked against Figure 22; the charge controller set to its LiFePO4 profile; polarity checked with a meter, not by wire colour; the battery's case undamaged; the enclosure closed apart from the door.
- **S4. Before the mast is left standing.** The earth rod, conductor and clamp are fitted and tight; every U-bolt nut is tight; no work on the mast when thunder is near.
- **S5. Before water is turned on.** Every clip, tee and plug is fitted; the supply is the tank and pump, not the hydrant main; the pressure is 2.5 bar or less.
- **S6. Before the pump-start contact is connected.** The pump keeps its own certified controls and ground-fault protection; the relay connects only to the pump's control input as its maker describes; any mains work is done by a qualified electrician; nothing in EmberGuard carries mains.
- **S7. Before the kit is left armed.** Every check of section 5 passes; the household knows that EmberGuard does not replace evacuation, home hardening or clearing the gutters, and that nobody stays behind for it.

## 7. Tools, skills and workspace

**Tools.** Hacksaw with a 24 teeth per inch blade, pipe cutter; bench vice with soft jaws and a 12 mm round former for bending bar; bench drill or a drill in a stand; drills 2 to 12 mm, step drill to 22 mm; taps M2.5, M3, M4 and M6 with their tap drills; countersink; files and deburring tool; scriber, square, rule, calipers and protractor; hand sheet folder (or hardwood blocks in the vice) and aviation snips for 1 mm stainless; hammer drill with masonry bits; spanners and sockets 10 and 13 mm; set of hex keys; spirit level and digital angle finder; extension ladder with a stand-off; polyethylene line cutter and a punch for the heads; soldering iron, ferrule crimper and wire strippers; multimeter; bench power supply with a current limit (0 to 15 V, 0 to 3 A); buckets, stopwatch and a pressure gauge.

**Skills.** Basic metalwork (marking out, sawing, drilling, tapping, bending bar, folding thin sheet), through-hole soldering and crimping, safe ladder work, and fixing to masonry or timber. All circuits are extra-low voltage, 12.8 V nominal. Any work on the pump's mains supply is outside this plan and is for a qualified electrician.

**Workspace.** A bench about 1.5 x 0.7 m with a metalwork corner kept apart from the electronics; level, firm ground at the gable end for the ladder; a second person for every step on the house.

**Personal protective equipment.** Safety glasses for cutting, drilling and soldering; cut-resistant gloves for sheet and bar; hearing protection for sawing and hammer drilling; dust mask for drilling masonry; no gloves near a turning drill.

## 8. Where the numbers come from

- Model and constructability checks: `cad/src/model.py` (`python cad/src/model.py --check`); STEP and STL exports in `cad/step/` and `cad/stl/`.
- Pictures: `cad/src/build_plan_media.py`, using `.kit/build_views.py`; written to `docs/05-build-plan/` and `cad/drawings/EGD-DWG-101` to `EGD-DWG-114`.
- General arrangement: `cad/drawings/EGD-DWG-001.pdf`, Rev P5.
- Calculations: `docs/04-calcs/01-sizing.md` (EGD-CAL-001 v0.6) and `docs/04-calcs/sizing.py`; line lengths and fill [C2], [C3], supply pressure [C4], mast and anchors [E3], [E4], pod arm [E5], sun shade [E7], enclosure temperature [F5], [F6].
- Bill of materials: `bom/bom.csv`.
- Decisions: `docs/decisions/0003-design-for-construction.md` (EGD-DDR-003), with EGD-DDR-001 and EGD-DDR-002; open items in `docs/06-design-decisions.md` (EGD-DEC-001).
- Requirements: `docs/03-requirements.md` (EGD-REQ-001 v0.9).

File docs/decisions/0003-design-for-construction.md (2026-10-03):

---
doc_id: EGD-DDR-003
title: EmberGuard design for construction
project: EmberGuard
doc_type: Design decision record
version: "0.4"
status: Draft
date: '2026-10-02'
author: Amish Chadha
license: CERN-OHL-S-2.0
revisions:
- version: "0.1"
  date: '2026-10-01'
  author: Amish Chadha
  change: Changes that make the concept physically buildable, with the reason for each; made under Amish's 2026-09-30 instruction to make the design physically buildable; open for his review
- version: "0.2"
  date: '2026-10-01'
  author: Amish Chadha
  change: Budget treated as a value-engineering target
- version: "0.3"
  date: '2026-10-02'
  author: Amish Chadha
  change: Accepted by Amish, including the recommendations for A2 and A3
- version: "0.4"
  date: '2026-10-02'
  author: Amish Chadha
  change: Product render note updated; appearance model brought to the constructable design
---

# 0003: Design for construction

- **Date:** 2026-10-01
- **Status:** accepted. Amish, 2026-10-02: "i approve your recommendations for all 555 open decisions." This covers every change in Tables 1 and 2 and the recommendations for A2 and A3 in Table 3, now decided as recommended and recorded in the design decisions register (EGD-DEC-001); A1 is a value-engineering note carried in the register. The changes were made under Amish's 2026-09-30 instruction to make the design physically buildable.

## Context

On 2026-09-30 Amish asked for every repo to get an illustrated prototype build plan and wrote: "If you are realising that the design cannot be built as per concept - fix the design assumptions to match and be physically feasible as you draw the illustrations." The concept model of EGD-DDR-002 showed what EmberGuard does but was a massing model: many parts overlapped, floated or had no fixing. Checking the model with build123d (intersection volumes and gaps between every pair of parts and against the reference house) found the problems in Table 1.

The changes keep what EmberGuard does: the mast's position, height and sensors, the pods' position 200 mm beyond each gutter end and 500 mm above the lip, the sensors' aim (10 degrees toward the house, 5 degrees down) and 55 x 35 degree view, the two spray zones with six heads each at 4 L/min, the ground unit's contents and the 12 V, no-mains, no-roof-penetration approach. Nothing here changes the pitch or the safety case. Every change is in `cad/src/model.py`, which now runs 103 constructability checks (`python cad/src/model.py --check`): parts that must touch do touch, parts that must not touch are apart by at least the stated clearance, and nothing stands in either thermal sensor's view. All 103 pass.

## Decision

*Table 1. Changes made to the model, the BOM and the calculations.*

| # | Problem in the concept | Change made | Why this way |
| --- | --- | --- | --- |
| P1 | The two standoff pipes ran straight into the mast's centre line, through the tube, joined by solid collars; at the wall each pipe butted onto a 12 mm plate, which would need welding to galvanized pipe. | Each standoff now passes 6 mm beside the mast, its centre 43 mm to the side, and a 100 x 100 x 6 mm aluminium crossover plate sits between them: two M8 U-bolts round the mast and two round the pipe. At the wall the pipe sits in a bought slip-on base flange (set-screw grip), bolted with four countersunk M8 screws to a 140 x 140 x 8 mm aluminium wall plate held by four M10 anchors. | The crossover clamp is the standard way to join two tubes at right angles without welding or drilling either. The flange needs no threads on the pipe. The wall plate keeps the 100 mm anchor spacing that EGD-CAL-001 used, so the 535 N anchor pull still stands [E4]. |
| P2 | The mast cable ran up the outside of the mast and through both standoff collars and the humidity sensor's arm. | The mast cable runs inside the 36 mm bore of the mast, leaves through a grommet in a plastic end cap at the mast foot, runs under the lower standoff to the wall and down it. The humidity and panel leads enter the tube through two grommeted 12 mm holes. | The tube protects the cable from embers and sun; nothing else needs a hole through it. |
| P3 | The solar panel floated 42 mm from the end of its arm, and it faced away from the equator side (+Y in the model) instead of toward it (-Y), as the precis gives. | The panel faces south (the equator side, -Y in the model) at 45 degrees on a bought pole-mount tilt bracket: a clamp on the mast, a short arm and a rail bolted to the panel frame. | Corrects the model to the stated design and gives the panel a fixing. The wind area and height are unchanged, so the mast check stands [E2], [E3]. |
| P4 | The humidity shield's plates floated on an arm that passed through one of them, and the arm only touched the mast. The anemometer's adapter was a solid block sitting on the open mast top. | The shield's five plates sit on a centre rod with an arm above them and a clamp on the mast. The anemometer and vane crossarm stand on a sleeve that slides 40 mm over the mast top with two set screws. | These are how the bought weather-station spares fit; the parts now have something to hold them. |
| P5 | The pod bracket ended in a solid clamp block sitting inside the end of the gutter (96,000 mm³ of overlap), with a 20 mm rod post and arm and no real fixing to the house. | A verge cleat (80 x 80 x 6 mm aluminium angle, 140 mm long) is screwed by two 8 mm coach screws to the end of the roof overhang (the verge or barge board), 30 to 170 mm in from the eave edge. A 40 x 6 mm flat bar arm, bent twice, is bolted flat on the cleat and carries a 6 mm pod plate on its top tab. The plate turns on an M8 pivot bolt and an M6 bolt in a curved slot locks the 10 degree aim; two spacers of different height under the pod give the 5 degree downward tilt. | A gutter is too thin to carry a pod 500 mm above it; the verge board is the strongest timber at the eave corner and is not part of the roof covering, so R11's "no roof penetrations" still holds. The arm stays clear of the roof, fascia and gutter by 8 mm and the pod by 18 mm. At 120 km/h the arm sees about 8 MPa (factor 19 on 6063-T6) and each coach screw about 70 N of pull [E5]. |
| P6 | The sensor looked down a 32 mm tube reaching 70 mm out of the pod, through a wall with no opening. A tube of 29 mm bore that long would cut the sensor's 55 x 35 degree view to about 23 degrees across. | The sensor's 9.2 mm can sits in a 9.5 mm window in the pod's west wall, its board screwed to the inside of the wall on four M2.5 screws over 1 mm washers. Outside, a short lens hood bent from 1 mm stainless (28 x 18 mm inside, 20 mm deep) shades the window. A new check builds the sensor's 55 x 35 degree view as a solid and confirms it clears the lens hood, the pod hood and the mount. | Keeps the full field of view, on which the gutter coverage of EGD-CAL-001 section A depends, while still shading the lens from above and the sides. |
| P7 | The hood was a 6 mm slab floating 2 mm above the pod with no fixing. | The hood is 1 mm stainless with 10 mm drip flanges, on four 15 mm M4 spacers screwed into the lid, overhanging the lens end by 40 mm. | Gives it a fixing and an air gap that keeps sun and radiant heat off the box. This adopts the spaced hood of the product appearance model (review note, 2026-09-26, item 3). |
| P8 | Inside the pod the node board was not modelled, and the sensor board filled the inside height exactly. | The node board stands on four 12 mm standoffs on the pod floor, clear of the two M6 bolts that come down from inside the pod to the pod plate. The pod cable enters through an M16 gland in the east wall. | Everything inside is fixed and reachable with the lid off. |
| P9 | The ground enclosure floated 5 mm off the wall with no fixing; the cables entered through its top; the controller, relay and battery floated inside (the battery 32 mm above the floor). | Four wall lugs at the back corners hold the box 2 mm off the wall on M8 screws into wall plugs. Inside, the box's gear plate sits on four studs; the controller and relay stand on standoffs on it; the battery stands on the floor against it, held by a strap. The cables enter through four M20 glands in the bottom, near the door, clear of the battery. The siren sits on the top on its gasket; the key switch goes through the door. | A sealed box is entered from below so water runs off the glands. |
| P10 | The valves and manifold floated 250 mm off the wall, held only by the spray lines, and the valves sat in line on the manifold, so a closed valve A would have shut off the water to valve B. | A 3 mm aluminium valve board on the wall carries the manifold in two stand-off pipe clips, 520 mm above the ground. Each valve hangs from its own tee on the manifold, so the zones are fed side by side; a third tee carries the pressure transducer. | The zones can now run independently, which the leeward-only rule (EGD-DDR-002, O4) needs. |
| P11 | Each riser stood free 250 mm from the gable wall for 2.2 m and passed up through the gutter's outer lip; the eave line floated 22 mm above the lip with no clips. | Each riser runs along the base of the gable wall and up its corner on saddle clips, turns out under the gutter at 2.3 m (one stand-off clip screwed into the fascia's lower edge), rises 8 mm in front of the gutter and turns along it. The eave line sits 20 mm in front of the lip and 30 mm above it in 24 gutter-lip clips (already in the BOM, now modelled); the heads sit on tees. | Every metre of line is now supported and nothing passes through the gutter. The zone lines are 17.5 m and 21.1 m (were 17.7 m and 21.3 m), so water reaches the farthest head in 54 s (was 55 s) [C2], [C3]; the supply still needs about 2.3 bar [C4]. |
| P12 | The pod cables ran through the air beyond the house corner; the mast earthing (item 17) was not modelled. | Each pod cable runs along its arm, round the verge, under the soffit and down the gable wall corner to the enclosure's bottom glands. A bonding clamp on the mast foot, a 16 mm² conductor held 40 mm off the wall (clear of the spray line along the wall base) and a 1.2 m earth rod 400 mm out from the wall are now in the model. | Every cable and conductor has a supported route that the build plan can show. |

*Table 2. Knock-on changes.*

| Item | Change | Reason |
| --- | --- | --- |
| Cost | BOM lines 1, 2, 7, 9, 13, 14 and 16 respecified, lines 1, 2, 9, 13 and 16 repriced: kit $689.00 against the $605 value-engineering target, USD 84 or 14 % over [G1]. R13 moves from met to over the target. `budget_usd` is unchanged (Table 3, A1). | Parts added for construction: flanges, crossover plates and U-bolts (+$32), pod mounts and lens hoods (+$18), panel tilt bracket (+$6), longer cables (+$3), valve board, clips, glands and strap (+$25). |
| Calculations | EGD-CAL-001 v0.4: line lengths, fill times and supply pressure from the new routes [C2] to [C4]; a new wind check on the pod arm and cleat [E5]; cost [G1]. | Follows the model. |
| Drawing | EGD-DWG-001 Rev P4; making sketches EGD-DWG-101 to 113 added. | Follows the model. |
| Documents | EGD-REQ-001 v0.6 (R5, R10, R11, R13), EGD-PRC-001 v0.6 (components, numbers, cost). | Follows the model. |
| Product renders | The appearance model `cad/src/product_model.py` was brought to the constructable design on 2026-10-02 (pod mount and lens hood, riser, panel facing the equator, valve board, sun shade) and the render scenes exported. The photoreal renders, `media/card.png` and `media/social-preview.png` are made on Amish's Mac next. | Blender is on Amish's Mac. |

*Table 3. Proposed for Amish; A2 and A3 accepted as recommended on 2026-10-02.*

| # | Question | Options | Recommendation |
| --- | --- | --- | --- |
| A1 | The kit now prices at $689 against the $605 value-engineering target (`budget_usd`, a hypothetical control target), USD 84 over. | No decision needed. The target stays $605. Savings worth trying, about $35: bolt the flanges straight to the wall without wall plates (about $10, but the anchor pull roughly doubles and must be rechecked), a plywood valve board (about $12), unbranded thermal breakouts (about $10 to $15); quotations at TRL 4 may also move the estimate. | Carry in the value engineering section of EGD-DEC-001. The added parts are what makes the kit buildable; the savings trade strength and quality for small sums. |
| A2 | The sensor can now sits open in the pod's west wall, sealed by an O-ring but with nothing in front of the lens. | (a) no window, as modelled; (b) a thin polyethylene window across the lens hood's mouth (passes long-wave infrared, cheap, melts in ember attack); (c) a germanium window (about $30 to $60 each). | (a) for the prototype; decide after the heated-target and ash trials at TRL 4. Accepted by Amish, 2026-10-02, with an ash-fouled lens case included in those trials. |
| A3 | The pod mount needs a sound timber verge (barge) board at each gutter end. Many houses have one; some have a metal verge or none. | (a) the verge cleat as modelled, confirmed at the site; (b) also draw a fascia-face bracket for houses without a timber verge, at the next revision. | (a) now, (b) when a co-design partner's houses are known (O1). Accepted by Amish, 2026-10-02. |

## Consequences

- `design_state: constructable` in `project.yaml`. The build plan EGD-BLD-001 shows every component and step in pictures generated from the model (`cad/src/build_plan_media.py`); decisions are indexed in the design decisions register EGD-DEC-001.
- With A2 accepted, the prototype has no window in front of the sensor and the TRL 4 trials include an ash-fouled lens case. With A3 accepted, the verge cleat is used and a sound timber verge is confirmed at each site.
- Requirement status: one not met (R6), one over its value-engineering target (R13), three at risk (R1, R2, R10), one not verifiable at TRL 3 (R11), seven met (EGD-CAL-001 v0.4). R13 is the only change.
- The product renders and storefront images need updating on Amish's Mac.
- The enclosure, thermal breakout, pod box, flange and U-bolts are chosen at TRL 4; their hole patterns must be checked then (register, items to confirm).

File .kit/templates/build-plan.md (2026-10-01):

---
doc_id: PRJ-BLD-001
title: Project prototype build plan
project: Project name
doc_type: Build plan
version: "0.1"
status: Draft
date: YYYY-MM-DD
author: Amish Chadha
license: CERN-OHL-S-2.0
revisions:
  - version: "0.1"
    date: YYYY-MM-DD
    author: Amish Chadha
    change: First build plan; design made constructable
---

# Project prototype build plan

**Plan, not yet built.** How to build the first proof-of-concept prototype, component by component. Building and testing to it is TRL 4 work. Decisions still to be made are kept in the design decisions register (`docs/06-design-decisions.md`), not here.

## 1. What you are building

Every component, pulled apart and numbered in build order

One short paragraph: what the prototype is, how many components, which are made and which are bought, and the main ways they are made.

## 2. What changed to make it buildable

| Component | The concept had | The buildable design has | Why |
| --- | --- | --- | --- |

## 3. Making the components

### 3.1 Component name

Making sketch

**What it is and what it is made from.**

**How to make it.**

1. Mark out ...
2. Cut ...

**How it fits the parts next to it.**

Close-up of the joint

**Check before moving on.**

## 4. Putting it together

### Step 1: ...

Step 1

## 5. First checks

| Check | Requirement | How | Pass when |
| --- | --- | --- | --- |

## 6. Safety stops

## 7. Tools, skills and workspace

## 8. Where the numbers come from

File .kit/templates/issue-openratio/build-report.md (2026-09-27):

---
name: Build report
about: Tell us what happened when you built, printed or tested part of this design
title: "Build report: "
labels: build-report
---

This is a research and educational prototype, not a medical device. It is a TRL 3 concept and is not released for fabrication. If you build any part of it, you do so at your own risk. Reports help everyone.

**What you built** (part, sub-assembly or test)

**Materials, tools and settings**

**What worked**

**What did not work, with photos or measurements if you have them**

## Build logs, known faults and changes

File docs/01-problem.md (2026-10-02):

---
doc_id: EGD-PRB-001
title: EmberGuard problem statement
project: EmberGuard
doc_type: Problem statement
version: "0.6"
status: Draft
date: '2026-10-02'
author: Amish Chadha
license: CERN-OHL-S-2.0
revisions:
- version: "0.1"
  date: '2026-09-24'
  author: Amish Chadha
  change: Initial scaffold
- version: "0.2"
  date: '2026-09-25'
  author: Amish Chadha
  change: Populate to TRL 2 (problem, users, context, constraints, out of scope, prior work with sources)
- version: "0.3"
  date: '2026-09-25'
  author: Amish Chadha
  change: TRL 3. Budget raised to $425 and tank-first water source decided (EGD-DDR-001); journal sources checked; Mitchell (2006) linked
- version: "0.4"
  date: '2026-09-25'
  author: Amish Chadha
  change: Recommendations accepted by Amish (DDR-002). Budget constraint at $575
- version: "0.5"
  date: '2026-09-26'
  author: Amish Chadha
  change: Budget approved by Amish ($605)
- version: "0.6"
  date: '2026-10-02'
  author: Amish Chadha
  change: First co-design partner to approach, decided on 2026-10-02 (EGD-DEC-001)
---

# EmberGuard problem statement

Wildfire embers ignite homes well ahead of the fire front, often in gutters, on roof edges and in debris near the eaves, while the occupants have evacuated and fire crews are elsewhere. A house that could sense an ember shower and wet its own most vulnerable edges for a few hours, without grid power and without drawing much water, would remove one common ignition path. EmberGuard is a low-cost, open, garage-buildable attempt at that for a single house.

## The problem

Post-fire investigations and reviews agree that most homes lost in wildland-urban interface (WUI) fires are ignited by embers (firebrands) and the small spot fires they start, rather than by direct flame contact from the main fire front ([Caton et al. 2017, Fire Technology](https://doi.org/10.1007/s10694-016-0589-z); [Maranghides and Mell 2009, NIST TN 1635](https://doi.org/10.6028/NIST.TN.1635)). Embers are lofted by wind and can land a kilometre or more ahead of the flame front ([Manzello et al. 2020, Progress in Energy and Combustion Science](https://doi.org/10.1016/j.pecs.2019.100801)). They collect where wind eddies drop them: in gutters full of dry leaves and needles, at the roof-to-wall junction, in corners and against vents. Fire-safety guidance for homeowners therefore stresses clean gutters, ember-resistant vents and a non-combustible zone next to the house ([CAL FIRE, Ready for Wildfire](https://readyforwildfire.org)). Structure loss in recent California fires correlates strongly with local factors near the house and with wind-driven events ([Syphard and Keeley 2019, Fire](https://doi.org/10.3390/fire2030049)).

Three gaps remain for an ordinary household:

- **Timing.** Ember showers can arrive hours before the flame front and continue after it passes, often at night, when no one is home. Gutter debris that was clean in spring may be full again by autumn.
- **Power and water.** Fires coincide with high wind and grid shutoffs. Utilities de-energize lines in fire weather ([CPUC, Public Safety Power Shutoffs](https://www.cpuc.ca.gov/psps)), so anything that needs mains power may be dead when it is needed. Municipal water pressure can also drop when many houses and fire crews draw at once, which is why fire agencies advise evacuees not to leave sprinklers running ([CAL FIRE, Ready for Wildfire](https://readyforwildfire.org)).
- **Cost and control.** Commercial exterior sprinkler systems exist, some with remote activation and foam or retardant (for example [Frontline Wildfire Defense](https://www.frontlinewildfire.com)), but they are priced for high-value homes, closed and cloud-dependent. Timer-based or manually started roof sprinklers waste water for hours before and after the embers arrive, or never start because no one is there.

## Users and context

| User | Need | Context |
| --- | --- | --- |
| Homeowner in a WUI area | Automatic protection of gutters and roof edges during ember attack while evacuated; low cost; runs through a power cut | Single-storey or two-storey house, pitched roof with gutters; seasonal fire weather with strong dry winds |
| Renter or low-income household | A removable kit that needs no roof penetration and no mains wiring | Cannot modify the building; limited budget |
| Rural property with a tank | Uses a limited stored supply (1,000 to 5,000 L) as efficiently as possible | Well or rainwater tank; pump on its own supply or a generator |
| Community wildfire group (Firewise-style) | An open design that neighbours can build, audit and maintain together; data on ember arrival | Neighbourhood preparedness programs, maker spaces |
| Fire service and researchers | Systems that do not rob hydrant pressure; logged ember arrival times and wind data after a fire | Post-fire investigations, WUI research |

## Constraints

- Garage-buildable prototype; the budget in `project.yaml` is $605 USD for kit parts, raised from $300 to $425 (EGD-DDR-001, D1) and then to $575 (EGD-DDR-002, O2) by Amish on 2026-09-25, and to $605 on 2026-09-26 to cover the revised priced BOM of $605 (EGD-CAL-001 v0.3, section G).
- Low-voltage only on the house (12 V DC nominal). No mains wiring by the homeowner; a mains pump is switched only through its own certified controls by a dry contact.
- Must work through a grid outage of at least three days with the system armed.
- Water draw small enough for a household tank or a domestic mains connection, well below the demand of a garden hose on full, so that it does not compete with fire-fighting supply.
- No roof penetrations: mast, cable and spray lines attach with clamps and brackets to walls, fascia and gutter lips.
- Must tolerate what arrives before the fire front: wind to about 120 km/h (75 mph) in gusts, smoke, ash, low humidity, radiant heat and ember impact. Survival once the flame front reaches the house is not required, but the electronics should fail to a safe state.
- Build from off-the-shelf parts: thermal array sensors, a weather-station anemometer, a common microcontroller, irrigation solenoid valves and micro-sprinklers.

## Out of scope

- Fighting the main fire front, direct flame contact or crown fire. EmberGuard wets edges against embers; it is not a fire-suppression system.
- Whole-roof or whole-property deluge systems, foam or retardant injection.
- Replacing evacuation, home hardening (ember-resistant vents, Class A roofing, gutter guards, defensible space) or professional fire protection.
- Certified detection for life safety. EmberGuard is not a smoke alarm or a listed fire detector.
- Design of the water source, tank or pump, and power for the pump in an outage (decided, EGD-DDR-001, D6). EmberGuard interfaces to an existing supply; the first design case is a tank with its own pump (D5).

## Prior work

- **Ember science.** Firebrand generation, transport and ignition of fuel beds are reviewed by [Manzello et al. 2020](https://doi.org/10.1016/j.pecs.2019.100801) and, for buildings, by [Caton et al. 2017](https://doi.org/10.1007/s10694-016-0589-z) and its companion on building components ([Hakes et al. 2017, Fire Technology](https://doi.org/10.1007/s10694-016-0601-7)). NIST case studies of the 2007 Witch Creek and Guejito fires and the 2018 Camp Fire document ember-driven ignitions and fire timelines ([NIST TN 1635](https://doi.org/10.6028/NIST.TN.1635); [NIST TN 2135](https://doi.org/10.6028/NIST.TN.2135)).
- **Exterior sprinklers.** Wind-driven wetting of a structure against embers was analysed by Mitchell ([2006, "Wind-enabled ember dousing," *Fire Safety Journal* 41](https://www.sciencedirect.com/science/article/abs/pii/S0379711206000567)), which argues that modest, well-placed water can be effective when it reaches the surfaces where embers land. Australia has a standard for bushfire water spray systems ([Standards Australia AS 5414-2012, *Bushfire water spray systems*](https://webstore.ansi.org/standards/sai/54142012)). Commercial systems such as [Frontline Wildfire Defense](https://www.frontlinewildfire.com) offer remote-activated roof and perimeter sprinklers.
- **Guidance and standards.** [NFPA 1140](https://www.nfpa.org) (Standard for Wildland Fire Protection, which absorbed NFPA 1144) covers structure ignition hazards in the WUI. California Building Code Chapter 7A sets WUI construction rules including ember-resistant vents. [CAL FIRE's Ready for Wildfire](https://readyforwildfire.org) gives homeowner hardening and evacuation advice.
- **Sensing.** Low-cost thermal array sensors such as the [Melexis MLX90640](https://www.melexis.com/en/product/MLX90640/) (32 x 24 pixels, 55 or 110 degree field of view) make continuous thermal watching of a roof edge affordable. Weather-station cup anemometers and vanes are cheap and robust.

No open, low-cost design was found that combines ember-specific sensing, wind and humidity arming, low water use and outage-proof operation. On 2026-09-25 the titles, authors and years of Caton et al. 2017, Hakes et al. 2017, Syphard and Keeley 2019, NIST TN 1635 and NIST TN 2135 were checked against their DOI records, and Manzello et al. 2020, Mitchell (2006), AS 5414-2012 and the MLX90640 datasheet were found by title; the agency and company home pages and NFPA 1140 were not re-checked (see `docs/REVIEW.md`).

## Open questions

- Which users to involve first, and through which partner: a Firewise-style neighbourhood group, a county fire-safe council or a university WUI research group? Decided by Amish on 2026-10-02: the first candidate to approach is a recognised Firewise USA neighbourhood group in a wildland-urban interface area whose houses have gable ends with timber verges; in Texas, through the Texas A&M Forest Service, which supports such groups. Not yet agreed with any partner (EGD-DDR-001, O1).
- The first target is a house with a tank and its own pump (decided by Amish, 2026-09-25, EGD-DDR-001, D5).
- Would local fire agencies support an automatic system that draws from mains during a fire, given the pressure concern? Needs a conversation before any field trial.

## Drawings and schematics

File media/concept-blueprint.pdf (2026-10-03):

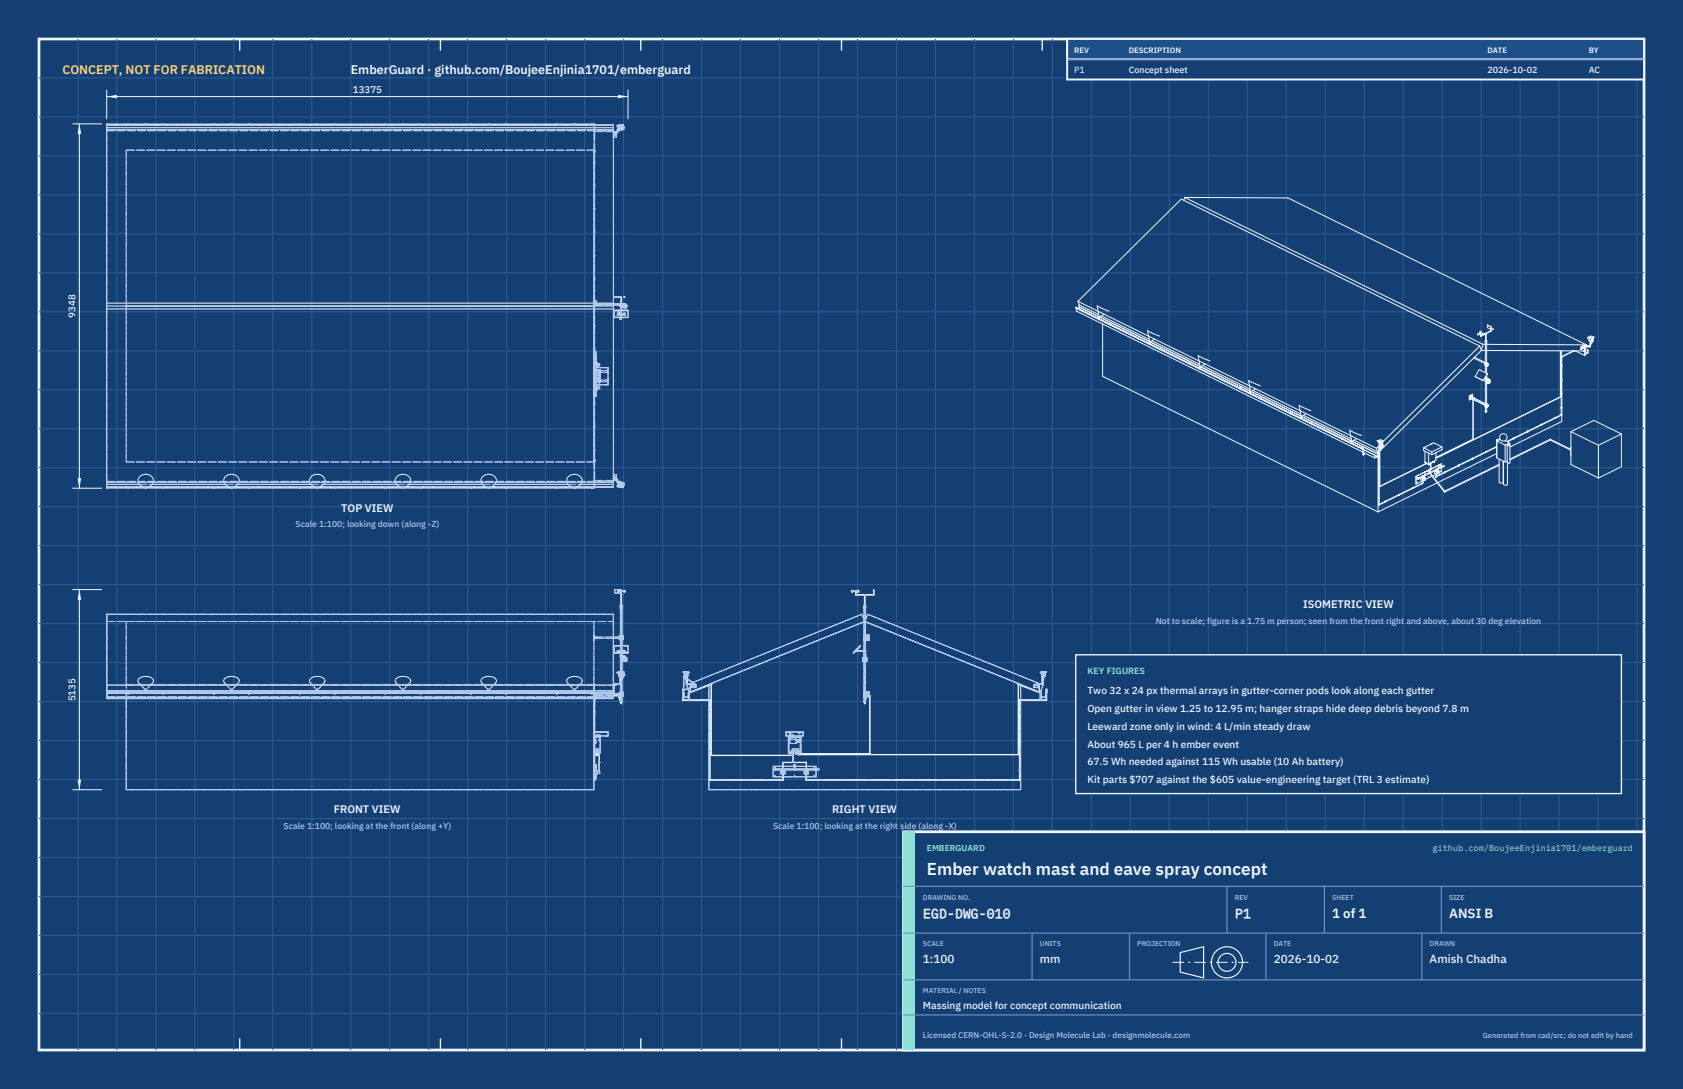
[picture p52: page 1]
CONCEPT, NOT FOR FABRICATION; EmberGuard · github.com/BoujeeEnjinia1701/emberguard; FRONT VIEW; TOP VIEW; RIGHT VIEW; ISOMETRIC VIEW; REV; DESCRIPTION; DATE; Concept sheet; EMBERGUARD; github.com/BoujeeEnjinia1701/emberguard; DRAWING NO. EGD-DWG-010; REV P1; SHEET 1 of 1; SIZE ANSI B; SCALE 1:100; UNITS mm; PROJECTION; DRAWN Amish Chadha; Licensed CERN-OHL-S-2.0 · Design Molecule Lab · designmolecule.com; Generated from cad/src; do not edit by hand

Scale 1:100; looking down (along -Z)

Not to scale; figure is a 1.75 m person; seen from the front right and above, about 30 deg elevation

KEY FIGURES
Two 32 x 24 px thermal arrays in gutter-corner pods look along each gutter
Open gutter in view 1.25 to 12.95 m; hanger straps hide deep debris beyond 7.8 m
Leeward zone only in wind: 4 L/min steady draw
About 965 L per 4 h ember event
67.5 Wh needed against 115 Wh usable (10 Ah battery)
Kit parts $707 against the $605 value-engineering target (TRL 3 estimate)

Scale 1:100; looking at the front (along +Y)

Scale 1:100; looking at the right side (along -X)

Ember watch mast and eave spray concept

MATERIAL / NOTES
Massing model for concept communication

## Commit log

2026-09-24 Initial scaffold: standard open hardware layout, CERN-OHL-S v2 + MIT licenses
    Claude-Session: https://claude.ai/code/session_01XuhhSU4W6fYhgCfURbrkut
    [bom.csv]
2026-09-25 Adopt portfolio kit v1.3.0: session commands, scale figure, 3D viewer, flow diagrams
    Adds .claude/commands (/populate, /advance-trl3, /rein-in, /refresh-media)
    so every Claude Code session starts from the standard prompts, and extends
    concept media with a 1.75 m scale figure, an interactive glTF viewer and
    system or energy flow diagrams. TRL cap 3 unchanged.
    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
2026-09-25 Kit v1.3.1: renderer fixes from the TremorTrace pilot
    Context scale parts for small objects, cutaway exclusions, and text
    labels in flow diagrams.
    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
2026-09-25 Populate emberguard to a strong TRL 2 with concept media (batch 7)
    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
    [bom.csv]
2026-09-25 Advance emberguard to TRL 3 (batches 7 and 8)
    Decisions approved by Amish 2026-09-25 recorded in DDR-001. TRL 4 is on hold.
    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
    [bom.csv, emberguard-kit.step, emberguard-kit.stl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]
2026-09-26 Accept all recommendations (DDR-002), switch footer to designmolecule.com, add README write-up with new inspiration point
    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
    [bom.csv, emberguard-kit.step, emberguard-kit.stl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]
2026-09-26 Strengthen sources, apply approved budgets, add CITATION.cff and CONTRIBUTORS.md with credits
    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
    [results.csv]
2026-09-27 Product appearance model and photoreal renders
    Adds cad/src/product_model.py (appearance model for renders only, all main
    dimensions from model.py) and Blender renders in media/render-*.png,
    captioned with the project, repository and viewing direction. README leads
    with the product render; trl stays 3.
    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
2026-10-01 Image quality pass: legible exploded views, flow diagrams and drawing sheets
    Kit 1.6.1 image layout: the parts list sits in its own column, number bubbles sit on visible parts and never overlap, small parts get a leader, pictures are cropped to the subject, flow labels keep numbers with their units, and sheet captions and the revision table no longer overprint. Concept images, blueprint and general arrangement sheet regenerated; repo-specific labels moved clear of other text and lines.
2026-10-01 Kit 1.7.0: constructable design, illustrated build plan and design decisions register
    The design is now constructable: every part can be made and fits its neighbours, with each change recorded in a Design for construction decision record (made under Amish's 2026-09-30 instruction; ope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
    [bom.csv, emberguard-kit.step, emberguard-kit.stl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]
2026-10-02 Record Amish's approval of the open-decision recommendations
    Amish approved the recommendation on every open decision in the design decisions register ("i approve your recommendations for all 555 open decisions.", 2026-10-02). Each decision is moved to Decisio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
2026-10-03 Carry approved follow-ups into the design and redo photoreal renders
    Amish approved the follow-up actions from the open-decision sign-off ("APPROVED CHANGES, COMPLETE THESE", 2026-10-02), the design-for-construction change tables in ten repos, the last wave's open dec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
    [bom.csv, emberguard-kit.step, emberguard-kit.stl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]

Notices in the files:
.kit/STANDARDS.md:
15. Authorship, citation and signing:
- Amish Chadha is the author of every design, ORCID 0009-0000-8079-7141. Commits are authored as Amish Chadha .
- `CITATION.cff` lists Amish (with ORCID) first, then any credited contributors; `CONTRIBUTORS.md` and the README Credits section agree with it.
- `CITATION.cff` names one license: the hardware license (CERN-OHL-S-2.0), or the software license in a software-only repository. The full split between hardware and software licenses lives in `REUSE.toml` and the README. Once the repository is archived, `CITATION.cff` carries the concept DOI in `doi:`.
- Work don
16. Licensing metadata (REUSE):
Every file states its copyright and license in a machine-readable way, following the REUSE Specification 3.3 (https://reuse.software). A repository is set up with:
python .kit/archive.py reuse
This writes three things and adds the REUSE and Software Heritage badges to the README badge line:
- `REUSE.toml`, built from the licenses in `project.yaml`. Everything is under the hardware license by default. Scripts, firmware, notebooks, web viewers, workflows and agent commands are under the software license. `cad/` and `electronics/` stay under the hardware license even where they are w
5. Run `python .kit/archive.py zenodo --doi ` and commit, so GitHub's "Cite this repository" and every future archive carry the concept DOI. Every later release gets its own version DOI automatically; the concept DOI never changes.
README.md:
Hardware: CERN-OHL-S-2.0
